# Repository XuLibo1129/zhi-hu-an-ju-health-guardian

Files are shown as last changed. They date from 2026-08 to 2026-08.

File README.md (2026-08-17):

# 基于 ESP32-P4 的多模态 AI 无感健康守护与交互终端系统

面向居家养老、独居老人和家庭健康守护场景的多模态无感监测系统。项目以 ESP32-P4 主终端为数据汇聚和交互中心，融合视觉跌倒检测、毫米波生命体征监测、Wi-Fi CSI 无线感知、语音交互、云端 AI 分析以及电话/短信求助能力，在不要求老人佩戴设备的情况下完成状态感知、风险判断、现场告警和远程查看。

> 本项目曾获**第九届全国大学生嵌入式芯片与系统设计竞赛东部赛区一等奖、全国三等奖（乐鑫赛道）**。

## 项目概览

### 解决的问题

传统手环、胸带等设备需要老人主动佩戴和维护，容易出现忘戴、没电或不适用的问题；单一摄像头方案又容易受到遮挡、光照和隐私因素影响。本项目采用多节点、异构传感器协同的方式，把不同感知手段放在各自擅长的位置：

- **视觉节点**负责识别人体姿态和明显跌倒动作。
- **毫米波雷达节点**负责无接触的人体存在、心率、呼吸率和跌倒辅助判断。
- **Wi-Fi CSI 节点**感知空间信道变化，为遮挡或弱光场景提供辅助证据。
- **ESP32-P4 主终端**负责数据接入、时间门控、融合判断、界面显示、语音交互和告警联动。
- **网页、微信小程序和 Android 客户端**负责远程查看、历史趋势和 AI 健康分析。

### 主要能力

| 能力 | 实现内容 |
| --- | --- |
| 无感生命体征监测 | 展示当前心率、呼吸率、人体存在状态和最近五天历史均值 |
| 多模态跌倒判断 | 视觉与毫米波作为主要证据，Wi-Fi CSI 作为环境辅助证据，并进行数据新鲜度检查 |
| 本地交互 | LVGL 触摸界面、语音唤醒/按住说话、语音播报和现场声光提示 |
| 远程查看 | 主终端通过 HTTP 提供状态与历史数据接口，三端客户端读取同一套数据 |
| AI 健康建议 | 对当前心率、呼吸率、告警状态和环境信息进行简短健康分析与建议 |
| 紧急求助 | 通过蜂窝通信模块执行手动或自动短信、电话告警 |
| 可复现实验 | 提供 CSI 采集、数据清洗、训练、回放和实时推理工具 |

## 系统架构

```mermaid
flowchart LR
    V[视觉节点\nK230 + YOLOv5n] -->|UART 单向状态| M[ESP32-P4 主终端]
    R[毫米波雷达节点\nESP32-P4] -->|HTTP POST| M
    T[ESP32-S3 CSI 发射端] -.->|Wi-Fi CSI 信道变化| X[ESP32-S3 CSI 接收端]
    X -->|特征 UDP| P[电脑端 CSI 推理工具]
    P -->|HTTP POST| M
    M -->|LVGL| S[屏幕与触摸交互]
    M -->|I2S 音频| A[麦克风与扬声器]
    M -->|UART| G[蜂窝通信模块]
    M -->|HTTP API| W[网页 / 微信小程序 / Android]
    M -->|HTTPS| C[LLM / ASR / TTS 服务]
```

### 数据流说明

1. 视觉节点周期性输出 `FALL` 或 `NOFALL` 状态，经 UART 单向发送到主终端。
2. 毫米波节点解析雷达数据，得到人体存在、心率、呼吸率和跌倒状态，经 HTTP 上报主终端。
3. 两块 ESP32-S3 组成 CSI 发射/接收链路，接收端提取 CSI 特征并通过 UDP 发送给电脑端工具。
4. 电脑端模型对 CSI 窗口进行推理、平滑和连续确认，再将结果通过 HTTP 上报主终端。
5. 主终端保存每个节点最近一次有效状态及时间戳，执行超时剔除和融合判断。
6. 主终端更新屏幕、历史数据和告警状态，同时向网页、小程序、Android 端提供查询接口。

## 核心技术路线

### 1. 视觉跌倒检测

视觉节点使用自行采集和标注的数据训练 YOLOv5n，并将模型转换为 K230/CanMV 可运行的 `kmodel`。设备端完成图像采集、推理、目标后处理和状态输出，主终端只接收简洁的状态结果，不传输持续视频流，降低通信负担并减少隐私暴露。

视觉节点脚本位于 `vision/k230/fall_detect.py`。由于摄像头存在倒装安装场景，脚本保留图像方向处理和 UART 状态输出逻辑；模型文件和训练数据不随仓库发布。

### 2. 毫米波生命体征与跌倒辅助判断

毫米波节点独立完成雷达串口接收、帧校验、有效数据解析和状态统计。节点不依赖主终端的实时计算，联网后按周期向 `/api/sensor/ld6002c` 发送 JSON，主终端按时间戳判断数据是否仍然有效。

示例数据：

```json
{
  "sensor": "ld6002c",
  "node_id": "ld6002c_01",
  "human": true,
  "heart_rate": 72.0,
  "breath_rate": 16.0,
  "fall_detected": false,
  "state": "normal",
  "frames": 120
}
```

### 3. Wi-Fi CSI 无线感知

CSI 工具链支持从 ESP32-S3 接收端获取 CSI 数据，完成以下处理：

```text
CSI 原始帧
  -> 解析 I/Q 数据
  -> 窗口切分与统计特征提取
  -> 基线校准与动态阈值
  -> RandomForest / ExtraTrees 模型比较
  -> 概率平滑与连续窗口确认
  -> HTTP 上报主终端
```

工具支持“空房、站立、走路、跌倒、坐下、弯腰捡东西”等动作标签，也支持串口采集、UDP 接收和 CSV 回放。CSI 对房间布局、人体位置、天线方向、热点信道和干扰较敏感，因此在系统中承担**辅助确认**角色，不能脱离视觉和毫米波单独作为最终报警依据。

### 4. 多模态融合与告警策略

主终端对视觉、毫米波和 CSI 分别维护有效标志、更新时间、状态和置信信息。融合前执行时间门控：超过新鲜度窗口、解析失败或通信中断的数据不参与当前判断。

当前工程采用面向嵌入式实时运行的证据组合规则：

- 视觉和毫米波是主要证据，CSI 是辅助证据。
- 单个辅助节点异常时，不直接覆盖主要节点的正常结果。
- 主要节点形成明确跌倒证据，且其他有效节点未明确否定时，进入告警确认。
- 连续窗口确认后才锁存告警，避免瞬时噪声触发。
- 告警锁存期间抑制重复拨号和重复短信；状态恢复并满足解除条件后清除锁存。

这套设计将“传感器判断”和“安全告警动作”分离，避免网络抖动、短时误判或某一个节点掉线直接导致错误报警。详细数据流和接口见 [docs/architecture.md](docs/architecture.md)。

### 5. AI 语音交互

主终端的 AI 能力与跌倒安全链路解耦：

- LLM：回答老人关于天气、日期、新闻和日常问题的对话请求。
- ASR：将麦克风采集的语音转换为文本。
- TTS：将 LLM 回复转换为语音并通过扬声器播放。
- AI 建议：根据当前心率、呼吸率、告警状态和天气生成简短健康建议。

LLM、ASR、TTS 均通过 ESP-IDF `menuconfig` 配置 URL、模型、音色和密钥；未配置云端服务时，传感器、屏幕和本地告警链路仍可独立运行。

## 仓库结构

```text
firmware/
  main-terminal/       ESP32-P4 主终端：UI、HTTP、融合、音频、历史数据和告警
  ld6002c-node/        ESP32-P4 毫米波雷达节点：串口解析和 HTTP 上报
  wifi-csi-tx/         ESP32-S3 CSI 发射端
  wifi-csi-rx/         ESP32-S3 CSI 接收端、CSI 特征输出和网络配置

vision/
  k230/                K230 视觉跌倒检测脚本和部署说明

tools/
  csi-toolkit/         CSI 采集、CSV 修复、数据分析、训练、回放和实时推理

clients/
  web-dashboard/       响应式网页端，支持桌面和手机布局
  wechat-miniapp/      微信小程序端
  android/             Kotlin + Jetpack Compose Android 客户端

hardware/
  enclosures/          主终端、雷达节点和 CSI 节点的可打印外壳文件

docs/
  architecture.md      系统架构、数据流和接口说明
  configuration.md      Wi-Fi、节点、云服务和客户端配置说明
```

## HTTP 接口

主终端默认监听 `8090` 端口，并提供跨域响应头，便于网页、小程序和局域网工具访问。

| 方法 | 路径 | 用途 |
| --- | --- | --- |
| `POST` | `/api/sensor/csi` | 接收 CSI 实时推理结果 |
| `POST` | `/api/sensor/ld6002c` | 接收毫米波节点结果 |
| `GET` | `/api/device/status` | 获取当前心率、呼吸率、节点状态和融合告警状态 |
| `GET` | `/api/device/history` | 获取最近五天历史心率、呼吸率数据 |

CSI 上报示例：

```json
{
  "sensor": "esp32_s3_wifi_csi",
  "node_id": "wifi_csi_01",
  "fall_probability": 0.82,
  "smooth_probability": 0.76,
  "threshold": 0.70,
  "alarm": true,
  "state": "疑似跌倒",
  "samples": 250
}
```

主终端返回的数据面向客户端使用，实际字段以 `app_device_agent.c` 和客户端数据适配代码为准。节点地址、端口和上报周期不要写死在公开源码中，应通过 `menuconfig` 或客户端设置配置。

## 快速开始

### 环境要求

- ESP-IDF 5.5.3，Windows 或 Linux 均可。
- Python 3.10 及以上，CSI 工具建议使用独立虚拟环境。
- K230/CanMV 对应的运行时、摄像头驱动和模型转换工具。
- Android Studio、微信开发者工具和现代浏览器，按需使用对应客户端。
- 实际部署时，主终端、毫米波节点、CSI 节点和电脑应处于同一局域网或手机热点网络。

### 编译 ESP-IDF 固件

先打开对应 ESP-IDF 环境，然后分别进入四个固件工程。以下命令以 PowerShell 为例：

```powershell
cd firmware\main-terminal
idf.py set-target esp32p4
idf.py menuconfig
idf.py build
idf.py -p COM5 flash monitor
```

毫米波节点：

```powershell
cd firmware\ld6002c-node
idf.py set-target esp32p4
idf.py menuconfig
idf.py build
idf.py -p COM13 flash monitor
```

CSI 发射端和接收端：

```powershell
cd firmware\wifi-csi-tx
idf.py set-target esp32s3
idf.py menuconfig
idf.py build

cd ..\wifi-csi-rx
idf.py set-target esp32s3
idf.py menuconfig
idf.py build
```

首次使用必须运行 `idf.py menuconfig`，配置 Wi-Fi、主终端地址、节点 ID、串口引脚和云服务参数。不同硬件版本的闪存大小、芯片修订版本和下载端口可能不同，不要直接照搬其他板卡的烧录参数。

### K230 视觉节点

1. 将训练后转换得到的 `yolov5n-falldown.kmodel` 放到设备存储卡的 `/sdcard/kmodel/`。
2. 根据 CanMV 固件版本安装对应的视觉运行时和摄像头驱动。
3. 将 `vision/k230/fall_detect.py` 上传到 K230 并运行。
4. 将 K230 的 UART TX 接到主终端视觉 UART RX，并连接公共 GND。
5. 确认串口输出为 `K230,FALL` 或 `K230,NOFALL`，再进行主终端联调。

模型权重、训练数据和原始比赛资料不包含在仓库中，需要使用者自行训练或准备兼容 K230 的模型文件。

### CSI 采集与训练

```powershell
cd tools\csi-toolkit
python -m venv .venv
.\.venv\Scripts\Activate.ps1
python -m pip install -r requirements.txt
python csi_viewer.py
```

采集流程：

1. 先启动 ESP32-S3 CSI 接收端。
2. 选择串口或 UDP 数据源，确认 CSI 帧持续到达。
3. 选择动作标签并设置固定采集时长。
4. 采集空房、正常活动、弯腰、跌倒等样本，保存为 UTF-8 BOM CSV。
5. 检查每类样本数量、采集位置和动作一致性。
6. 运行训练脚本并用实时 GUI 进行回放验证。

```powershell
python train_csi_model.py
python csi_realtime_gui.py
```

训练脚本会比较 RandomForest 和 ExtraTrees，并保存表现更好的模型。实际部署前应在最终的 AP/STA 拓扑、房间布局、天线位置和人员距离下重新采集数据，不建议直接使用其他房间的模型。

### 网页客户端

```powershell
cd clients\web-dashboard
python -m http.server 8080
```

浏览器打开 `http://127.0.0.1:8080`，在页面中填写主终端地址，例如 `http://192.168.1.100:8090`。网页支持桌面和手机布局，可查看实时生命体征、融合告警、历史数据和节点信息。

网页端的 DeepSeek 健康分析需要用户在页面中配置自己的 API Key。公开部署时不要把密钥长期放在浏览器端，建议改为受控后端代理或企业级密钥管理服务。

### 微信小程序与 Android 客户端

- 微信小程序工程位于 `clients/wechat-miniapp`，使用微信开发者工具打开该目录。
- Android 工程位于 `clients/android`，使用 Android Studio 打开该目录。
- 两端都需要先将设备和手机接入同一网络，再在设置中填写主终端地址。
- 微信开发者工具调试局域网 HTTP 时，需要按开发者工具要求关闭合法域名校验；正式发布应配置 HTTPS 合法域名。
- Android 工程已允许局域网 HTTP 明文访问，正式部署时建议改为 HTTPS 或受控网关。

Android Debug 构建：

```powershell
cd clients\android
.\gradlew.bat assembleDebug
```

## 配置与安全

详细配置见 [docs/configuration.md](docs/configuration.md)，系统数据流见 [docs/architecture.md](docs/architecture.md)。

以下内容不得提交到 Git：

- Wi-Fi SSID 和密码、真实局域网 IP、热点密码。
- LLM、ASR、TTS、天气和 DeepSeek API Key。
- 紧急联系人手机号、蜂窝通信凭据和 Access Token。
- `sdkconfig`、`.env`、模型权重、原始数据集和包含隐私信息的日志。
- 现场演示专用模拟代码、比赛提交材料和本地语音中转服务。

建议使用 `idf.py menuconfig` 写入本地配置，发布前检查 `git status` 和 `git diff --cached`，确认没有密钥、手机号和真实网络参数。

## 测试与已知限制

当前工程已完成以下基础验证：

- ESP32-P4 主终端、毫米波节点使用 ESP-IDF 5.5.3 构建通过。
- ESP32-S3 CSI 发射端和接收端使用 ESP-IDF 5.5.3 构建通过。
- CSI 采集、训练和实时推理脚本可运行。
- 网页、微信小程序和 Android 客户端均保留主终端状态与历史数据接口。

使用时需要注意：

1. 这是健康守护和安全提醒系统，不是医疗器械，心率、呼吸率和跌倒结果不能替代医生诊断。
2. CSI 结果会受到房间布局、无线干扰、人体位置和天线方向影响，必须进行现场校准。
3. 视觉检测受摄像头视野、遮挡、光照和模型训练数据影响。
4. 毫米波雷达需要稳定供电、正确串口电平和合适安装角度。
5. 云端 AI、ASR、TTS 和天气服务依赖网络，未配置或网络中断时不应影响本地传感器和告警链路。
6. 自动电话和短信属于高风险动作，现场部署前应先使用测试号码并配置重复触发抑制。

## 开源范围

本仓库公开可复现的工程代码、客户端、工具、配置模板、架构文档和 3D 打印外壳文件。以下内容不随仓库发布：

- 训练数据集和模型权重。
- 比赛研究报告、答辩材料和现场演示专用页面。
- 本地语音中转服务、真实密钥、手机号和网络配置。
- 第三方 SDK、字体、模型运行时和传感器厂商资料。

使用第三方组件时，请遵守其原始许可证、服务条款和数据保护要求。

## 许可证

本项目代码、文档和硬件外壳文件采用 [MIT License](LICENSE) 发布。第三方 SDK、字体、模型运行时、开发板资料和传感器资料仍以其原始许可证或厂商条款为准。

欢迎通过 Issue 反馈可复现的问题，也欢迎提交围绕传感器适配、数据处理、客户端体验和部署文档的改进建议。

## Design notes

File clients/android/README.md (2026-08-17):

# 健康守护终端安卓 App

技术栈：

```text
Kotlin + Jetpack Compose + Material 3
```

默认主控地址示例：

```text
http://192.168.1.100:8090
```

用 Android Studio 打开本目录：

```text
当前目录
```

工程已经允许局域网 HTTP 明文访问：

```xml
android:usesCleartextTraffic="true"
```

“AI 健康分析”直接请求 DeepSeek，API Key 在 App 中填写并保存在本机设置中，不会写入项目源码。

使用工程自带的 Gradle Wrapper 构建：

```powershell
.\gradlew.bat assembleDebug
```

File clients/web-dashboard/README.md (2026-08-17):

# 基于 ESP32-P4 的多模态 AI 无感健康守护与交互终端系统

这是面向主终端的真实状态查看网页，支持电脑布局和手机布局。网页从主终端读取生命体征、节点状态、融合结果和最近五天历史数据，也可以在浏览器中直接调用 DeepSeek 对当前数据进行健康分析。

## 使用

1. 将电脑和主终端接入同一局域网。
2. 用静态文件服务器打开当前目录，例如：

   ```powershell
   python -m http.server 8080
   ```

3. 在网页的“主控地址”输入主终端地址，例如 `http://192.168.1.100:8090`。
4. 点击“连接”，确认浏览器允许访问局域网 HTTP 服务。

网页不会内置 API Key。DeepSeek Key 只保存在浏览器本地存储，生产部署时建议通过后端代理或企业密钥管理服务保护密钥。

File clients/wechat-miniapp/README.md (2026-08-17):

# 健康守护终端微信小程序

默认主控地址：

```text
http://192.168.1.100:8090
```

入口页面：

```text
miniprogram/pages/index/index
```

开发者工具中如需访问局域网 HTTP 地址，调试阶段请在详情里关闭“校验合法域名、web-view、TLS 版本以及 HTTPS 证书”。

“AI 健康分析”直接请求 DeepSeek。发布前需要在微信公众平台将以下地址加入 request 合法域名：

```text
https://api.deepseek.com
```

API Key 在小程序页面中填写并保存在微信本地存储，不会写入项目源码。

检查 TypeScript：

```powershell
npm run typecheck
```

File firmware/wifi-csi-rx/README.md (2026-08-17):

# wifi_csi_rx

ESP32-S3 Wi-Fi CSI receiver. It starts a SoftAP, receives UDP packets from the
TX board, enables Wi-Fi CSI, and outputs six-channel CSI features:

```text
rssi,mean_amp2,amp2_8,amp2_24,amp2_48,amp2_80
```

The features can be printed to serial and forwarded to the PC inference tool
over UDP.

When AP+STA is enabled, the A board may also receive CSI from the phone hotspot
router link. The firmware therefore enables `CSI source MAC filter = auto` by
default. In auto mode it prefers MAC addresses of stations connected to the A
board SoftAP, so the B-board link is forwarded and the phone-hotspot link is
dropped. If no SoftAP station is known yet, it falls back to short auto-learning.

Default link:

```text
SSID: CSI_RX_AP
Password: configure it in `idf.py menuconfig` before flashing.
Channel: 6
SoftAP IP: 192.168.4.1
UDP port: 3333
Feature UDP target: configure your computer IP, port 34567
Max clients: 2
```

Keep the PC on the same router/hotspot as the A-board STA and let the PC GUI
listen on UDP port `34567`.

If auto-learning picks the wrong source, set `CSI source MAC filter` in
`idf.py menuconfig` to the B-board MAC, for example:

```text
e0:72:a1:d2:42:68
```

For final deployment, enable AP+STA in `idf.py menuconfig`:

- `Also connect A board to router as STA`: enabled
- `Router STA SSID` / `Router STA password`: router or phone hotspot
- `CSI feature UDP target IP`: PC IP on the router LAN

B board still connects to `CSI_RX_AP`; the PC and main ESP32-P4 terminal stay
on the router network.

Build:

```powershell
idf.py set-target esp32s3
idf.py build
```

Expected serial output:

```text
-42,1234,99,1200,880,240
I (...) wifi_csi_rx: STAT csi_hz=50 udp_hz=50 forward_hz=50 ...
```

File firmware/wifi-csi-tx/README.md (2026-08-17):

# wifi_csi_tx

ESP32-S3 Wi-Fi CSI transmitter. It connects to the receiver SoftAP and sends
UDP packets at a fixed interval so the receiver can collect CSI.

Default link:

```text
SSID: CSI_RX_AP
Password: configure it in `idf.py menuconfig` before flashing.
Receiver IP: 192.168.4.1
UDP port: 3333
Packet interval: 20 ms
```

Build:

```powershell
idf.py set-target esp32s3
idf.py build
```

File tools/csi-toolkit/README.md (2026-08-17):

# ESP32 CSI 无线感知波形工具

这是给 ESP32-S3 Wi-Fi CSI 接收端用的串口波形工具，支持实时看波形、切换动作标签、保存 CSV 数据。

支持的串口格式：

```text
-25,1830,244,185,3200,4100
CSI_DATA,1,aa:bb:cc:dd:ee:ff,-42,...,[...]
```

启动：

```powershell
cd D:\Users\XLB\Desktop\esp32_csi_viewer
.\run.ps1
```

使用：

1. A 板烧录并运行 `wifi_csi_rx`。
2. 启动 `csi_viewer.py`，或直接运行 `run.ps1`。
3. 选择 A 板 COM 口，波特率保持 `115200`，点击“连接”。
4. 采集前选择“空房”“走路”“坐下”“跌倒”“弯腰捡东西”等标签。
5. 设置“采集时长(s)”，点击“开始记录”保存 CSV 数据，到时间会自动停止，默认放在 `data` 文件夹。
6. CSV 使用带 BOM 的 UTF-8 保存，直接用 Excel 打开中文不会乱码。

如果之前保存过乱码 CSV，可以转换旧文件：

```powershell
cd D:\Users\XLB\Desktop\esp32_csi_viewer
python .\fix_csv_encoding.py
```

训练 Wi-Fi CSI 辅助跌倒模型：

```powershell
cd D:\Users\XLB\Desktop\esp32_csi_viewer
python .\train_csi_model.py
```

默认训练二分类模型：`fall` / `non_fall`。输出会保存到 `models` 文件夹。

默认训练会自动比较随机森林和 ExtraTrees，并选择交叉验证表现更好的模型。当前建议稳定运行阈值是 `0.50`，适合作为主终端融合视觉/雷达时的辅助信号。如果只想查看六分类效果：

```powershell
python .\train_csi_model.py --mode multiclass
```

实时推理：

推荐直接打开图形界面：

```powershell
.\start_realtime_gui.bat
```

也可以手动运行：

```powershell
python .\csi_realtime_gui.py
```

界面里可以选择 A 板串口、选择模型、调阈值、调连续确认窗口，并实时查看跌倒概率。
实时推理现在带有开场环境校准和运动门控。点击“开始UDP接收”后，前几个校准窗口内尽量保持空房/无人移动，让软件学习当前 AP+STA、手机热点和房间状态的基线。日志里的“动态阈值”会随基线自动抬高，用来压住空房误报。

如果 A 板不想一直插电脑串口，可以走 UDP：

1. A 板 `wifi_csi_rx` 当前把六路特征发送到电脑的 `34567` UDP 端口。
2. 电脑与 A 板 STA 连接同一个路由器或手机热点。
3. 打开实时推理界面后会自动监听 UDP `34567`；停止后也可手动点击“开始UDP接收”。
4. B 板继续连接 A 板热点并发送 UDP 包，界面收到数据后会直接进入模型判断。

命令行 UDP 接收也可以这样运行：

```powershell
python .\csi_realtime_infer.py --udp-port 34567
```

正式接主终端时建议切到同一个路由器网络：

1. 电脑、主终端 ESP32-P4 连接同一个 2.4GHz 路由器/手机热点。
2. A 板在 `idf.py menuconfig` 里打开 `Also connect A board to router as STA`，填路由器 SSID/密码。
3. 把 `CSI feature UDP target IP` 从默认 `192.168.4.255` 改成电脑在路由器里的 IP。
4. B 板仍然只连接 A 板热点 `CSI_RX_AP`，不需要改。
5. GUI 继续点“开始UDP接收”，识别结果再通过“主终端URL”发给 ESP32-P4。

如果 AP+STA 模式下效果仍然差，直接在最终拓扑下补采数据：

1. 打开 `csi_viewer.py` 或 `run.ps1`。
2. 不选串口，UDP端口保持 `34567`，点击“UDP连接”。
3. 在当前 A板AP+STA、B板连接A板、电脑连接手机热点的状态下，重新采集 `空房`、`站立`、`走路`、`跌倒` 等短样本。
4. 重新运行 `python .\train_csi_model.py`，再用最新模型做实时测试。

发送结果到主终端：

1. 主终端开一个 HTTP 接收接口，例如 `http://主终端IP:8090/api/sensor/csi`。
2. 在实时推理界面的“主终端URL”里填入这个地址。
3. 点击“测试发送”，日志显示成功后再开始实时检测。

发送的 JSON 格式大致如下：

```json
{
  "sensor": "esp32_s3_wifi_csi",
  "node_id": "wifi_csi_01",
  "time": "2026-07-06T15:56:00",
  "fall_probability": 0.82,
  "smooth_probability": 0.76,
  "threshold": 0.70,
  "alarm": true,
  "state": "疑似跌倒",
  "samples": 250
}
```

命令行版本仍然保留：

```powershell
python .\csi_realtime_infer.py --port COM8
```

把 `COM8` 换成 A 板实际串口。脚本会加载 `models` 文件夹里最新的二分类模型，输出 `p_fall`、平滑概率和 `正常/预警中/疑似跌倒`。默认阈值是 `0.50`，连续 4 个窗口超过阈值才报警。GUI 里也提供“稳定运行”和“灵敏测试”两个预设按钮。

如果现场仍然误报，先用更保守的参数：

```powershell
python .\csi_realtime_infer.py --port COM8 --threshold 0.85 --confirm-windows 6
```

用已有 CSV 回放测试：

```powershell
python .\csi_realtime_infer.py --replay .\data\csi_20260706_152250_跌倒.csv --print-normal
```

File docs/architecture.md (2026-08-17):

# 系统架构

## 数据流

```text
K230 视觉节点 ──UART──┐
毫米波雷达节点 ─HTTP──┼──> ESP32-P4 主终端 ──HTTP/局域网──> Web / 小程序 / Android
CSI 接收端 ──HTTP─────┘             │
                                    ├──LVGL 触摸界面
                                    ├──SD 卡历史心率/呼吸率
                                    ├──A7670C 电话/短信
                                    └──云端 LLM / ASR / TTS
```

## 主终端职责

主终端只保存各节点最近一次有效数据，并为每条数据记录时间戳。节点超过新鲜度窗口后不会继续参与跌倒判定。融合流程包含：

1. 读取视觉、毫米波和 CSI 的有效状态。
2. 对超时、无效和通信中断数据做时间门控。
3. 视觉和毫米波作为主证据，CSI 作为辅助证据；主终端依据有效证据组合生成融合分数。
4. 达到阈值后进行告警锁存，避免同一事件重复触发；恢复正常后解除锁存。

CSI 的训练和窗口特征提取在 `tools/csi-toolkit` 中完成。由于 CSI 对环境、天线摆放和信道变化敏感，它在系统中承担辅助确认作用，不单独决定最终告警。

## 节点接口

- K230：主终端 UART RX 接收 K230 的单向状态行，建议格式为 `K230,FALL` 或 `K230,NOFALL`。
- 毫米波节点：周期性向主终端 `POST /api/sensor/ld6002c` 发送 JSON。
- CSI 推理工具：周期性向主终端 `POST /api/sensor/csi` 发送 JSON。
- 主终端：提供 `GET /api/device/status` 和 `GET /api/device/history`，供三端客户端读取。

## AI 交互

AI 功能与跌倒安全链路解耦。LLM 负责对话和健康建议，ASR 负责语音转写，TTS 负责播放文本；三者都通过 menuconfig 配置 URL、模型和密钥，未配置时主终端仍可运行本地界面和传感器链路。

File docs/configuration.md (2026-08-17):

# 配置说明

## 主终端

进入 `firmware/main-terminal` 后执行 `idf.py menuconfig`，重点配置：

- `Dual Agent Console -> Wi-Fi SSID / password`
- `Cloud LLM -> URL / model / API key`
- `Cloud ASR -> URL / model / API key`
- `Cloud TTS -> URL / model / voice / API key`
- `A7670C -> emergency phone`，以及自动短信、自动电话开关
- `K230 vision UART` 和 `Radar UART` 引脚

主终端默认天气位置是南京市江北新区；经纬度和天气站点可以在 menuconfig 调整。

## 毫米波节点

在 `firmware/ld6002c-node` 配置：

- Wi-Fi SSID 和密码
- 主终端 URL，例如 `http://192.168.1.100:8090/api/sensor/ld6002c`
- 节点 ID、UART 引脚和上报周期

仓库中的 `192.168.1.100` 只是示例地址，必须换成实际主终端地址。

## CSI 节点

接收端建立 SoftAP，发射端连接该 AP。接收端可选用 STA 同时连接路由器或手机热点，再把特征 UDP 发到电脑。电脑端推理工具将判定结果通过 HTTP 发给主终端。

不要把真实 Wi-Fi 密码、电脑 IP 或主终端 IP 写入源码。推荐在 `idf.py menuconfig` 中设置，发布前保留 `sdkconfig.defaults` 中的空值或示例值。

## K230

将 YOLOv5n 跌倒检测模型以 `yolov5n-falldown.kmodel` 放在设备的 `/sdcard/kmodel/` 下，再运行 `vision/k230/fall_detect.py`。模型权重不在仓库中；需要根据 K230/CanMV 版本安装相应运行时和驱动。

## 客户端

网页、小程序和 Android 默认使用 `http://192.168.1.100:8090` 作为示例地址。实际使用时在网页输入框、小程序设置或 Android 设置页中修改为主终端当前地址。移动端访问局域网 HTTP 服务时，还需要满足微信开发者工具、Android 明文流量和目标网络的权限要求。

## 密钥管理

API Key、Access Token、手机号和语音服务凭据只能放在本地配置或受控服务中。不要把它们写入 Git、截图、日志、README 或固件二进制。

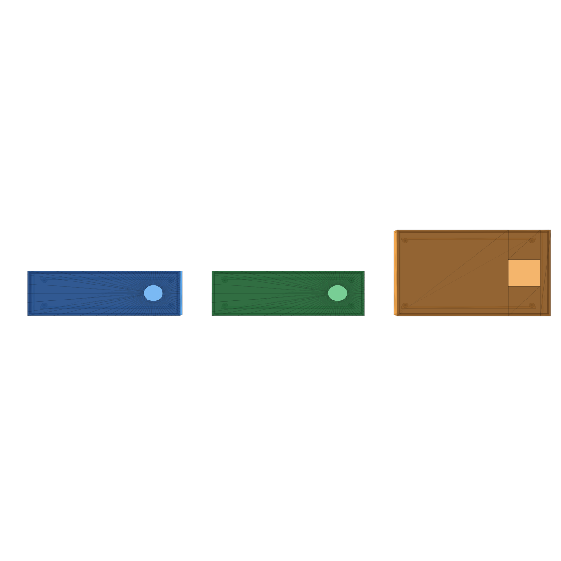
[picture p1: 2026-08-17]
hardware/enclosures/sensor-nodes/??????_????.png

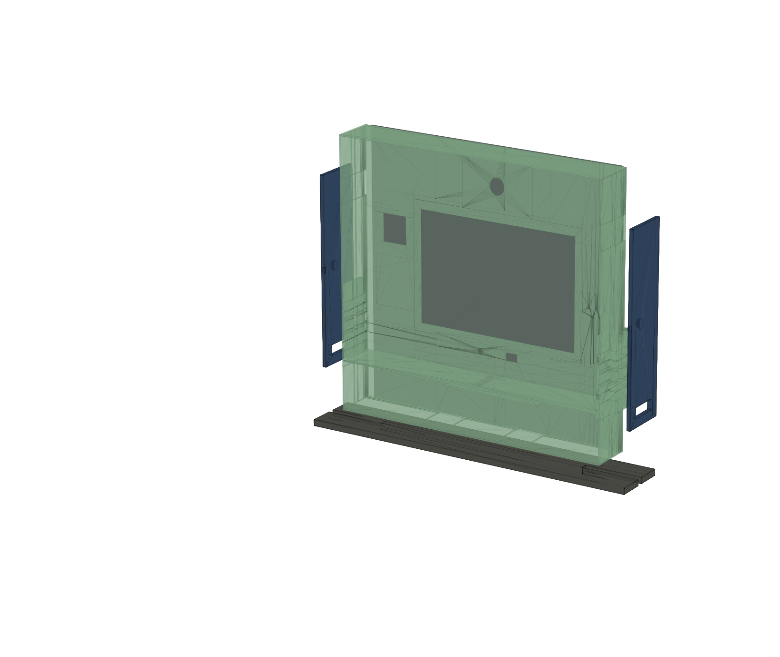
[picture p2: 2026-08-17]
hardware/enclosures/main-terminal/????_????.png

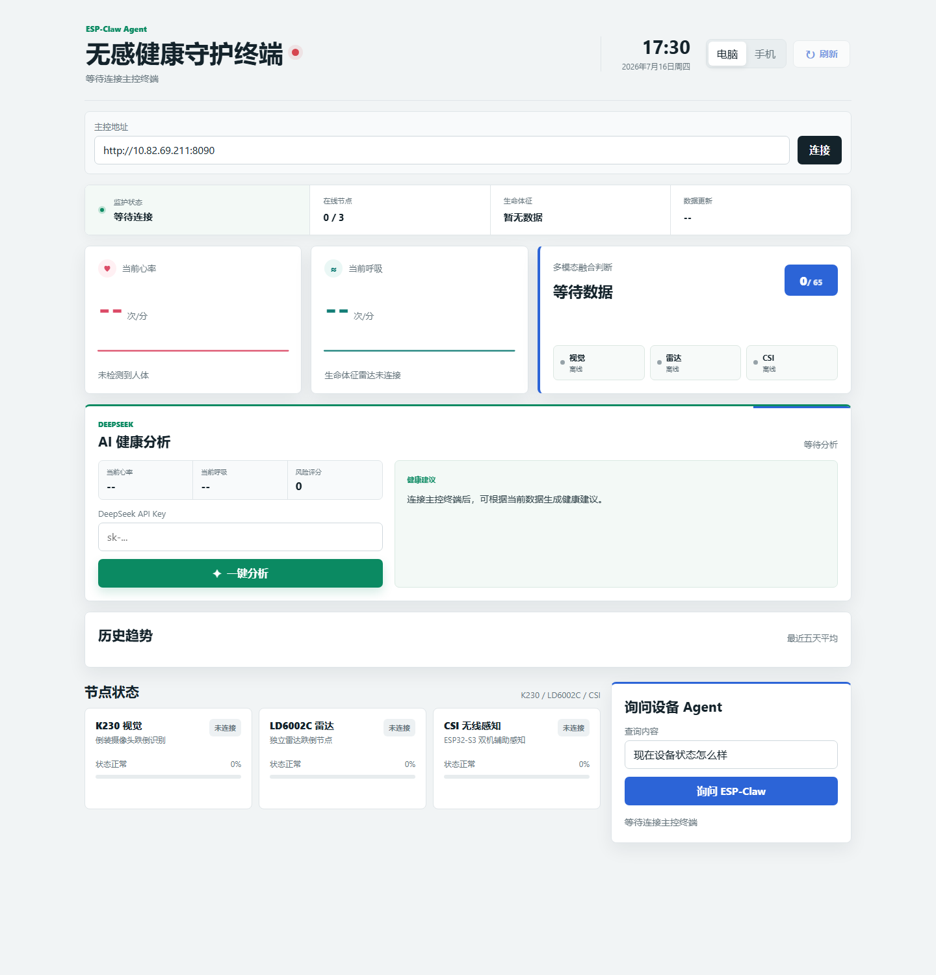
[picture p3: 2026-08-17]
clients/web-dashboard/dashboard-desktop.png

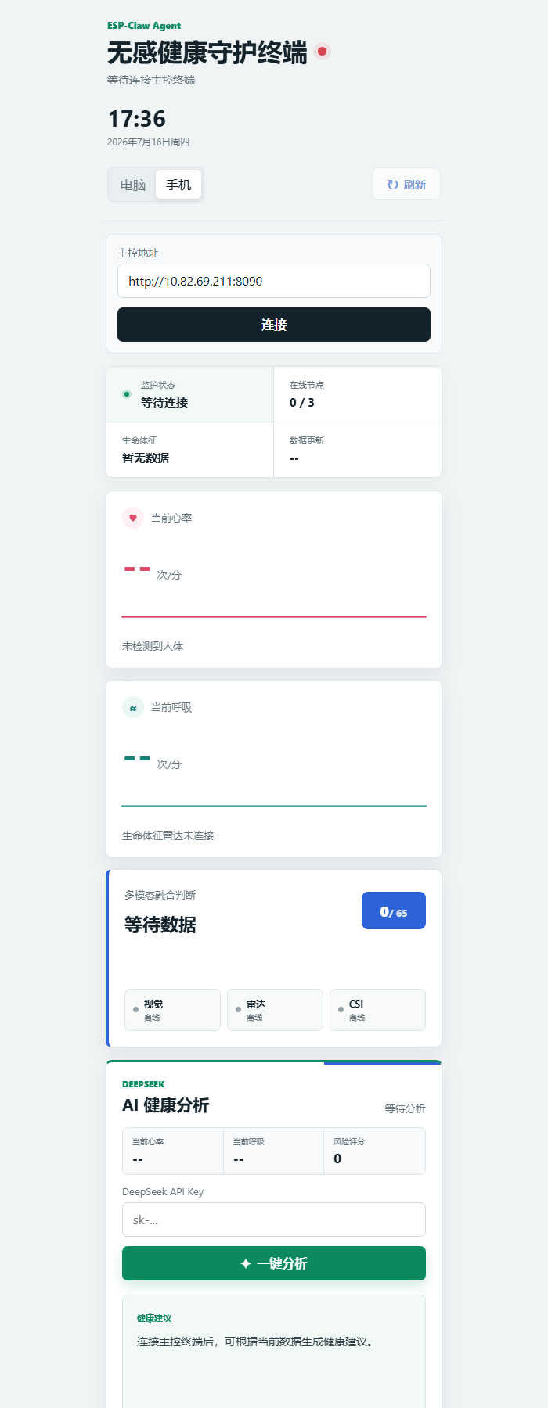
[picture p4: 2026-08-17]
clients/web-dashboard/dashboard-phone-mode.png

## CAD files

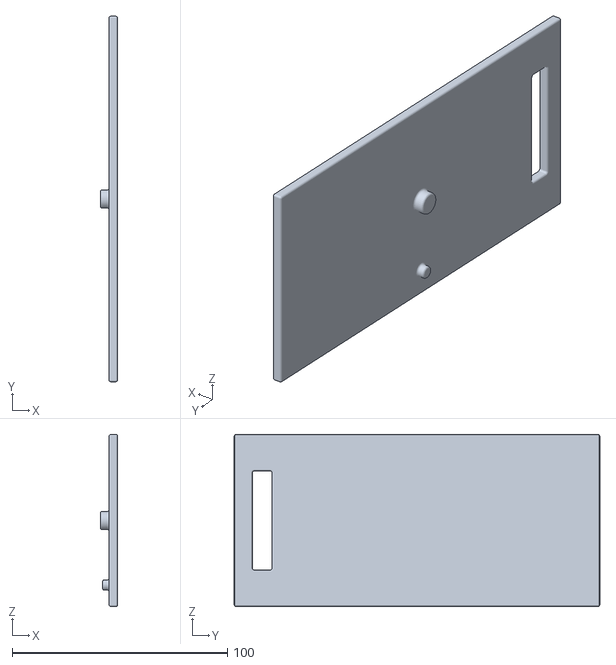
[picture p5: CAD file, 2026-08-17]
hardware/enclosures/main-terminal/???_??2?_?????.STL
8.00 x 170.0 x 80.0

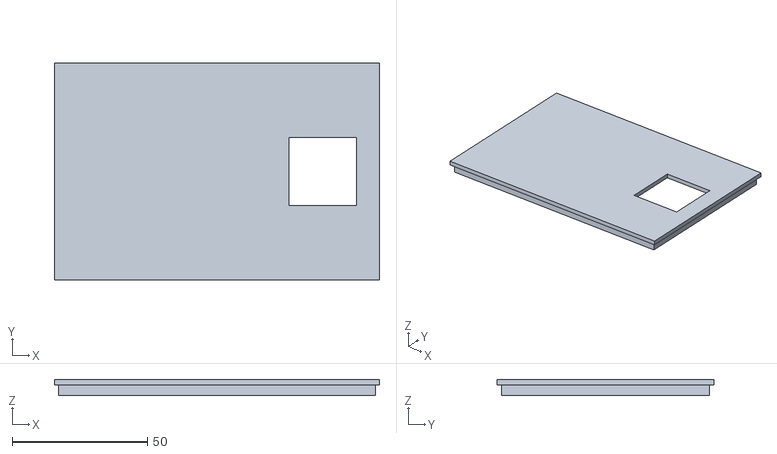
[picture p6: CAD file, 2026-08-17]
hardware/enclosures/sensor-nodes/LD6002????_??_25x25??.STL
120.0 x 80.0 x 6.00

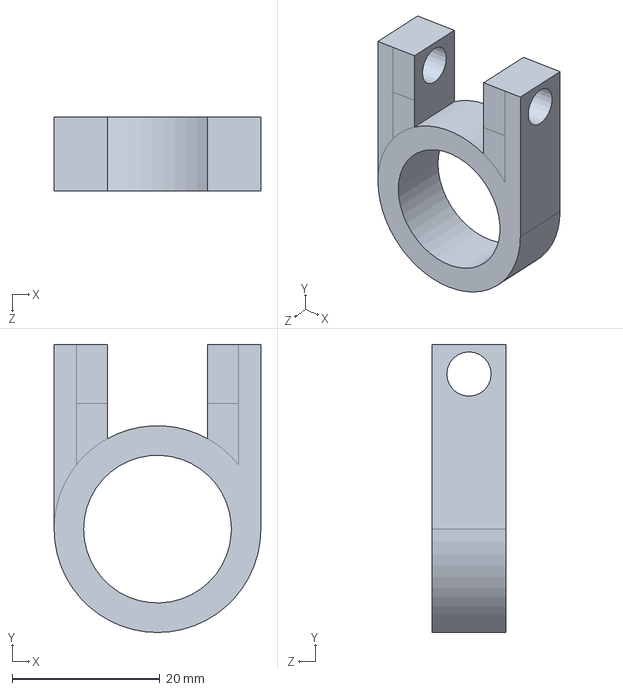
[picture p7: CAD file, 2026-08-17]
hardware/enclosures/main-terminal/???????.SLDPRT
28.0 x 39.0 x 10.0 mm

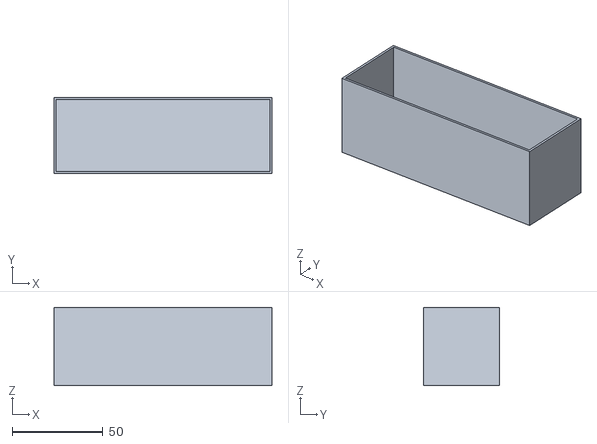
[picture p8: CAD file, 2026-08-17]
hardware/enclosures/sensor-nodes/WiFi_CSI_A??_??_?????.STL
120.0 x 42.0 x 43.0

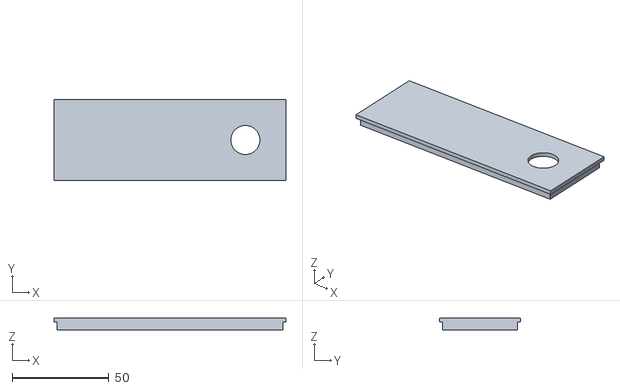
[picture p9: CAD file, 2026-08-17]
hardware/enclosures/sensor-nodes/WiFi_CSI_A??_??_15mm??.STL
120.0 x 42.0 x 6.00

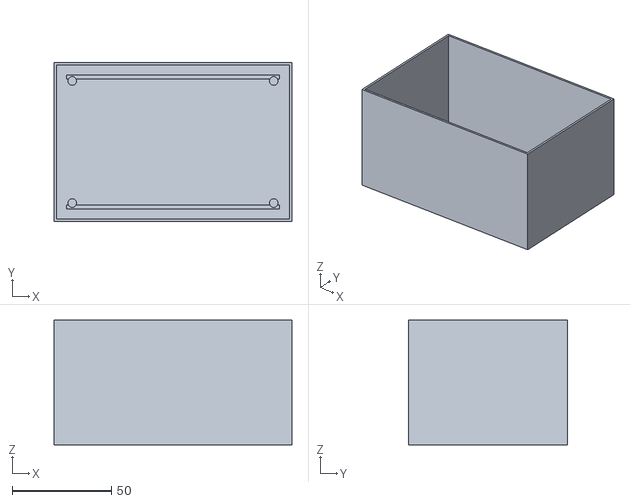
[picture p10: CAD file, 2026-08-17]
hardware/enclosures/sensor-nodes/LD6002????_??_?????.STL
120.0 x 80.0 x 63.0

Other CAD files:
hardware/enclosures/sensor-nodes/WiFi_CSI_B??_??_15mm??.STL
hardware/enclosures/sensor-nodes/WiFi_CSI_B??_??_?????.STL
hardware/enclosures/main-terminal/????_????.STL
hardware/enclosures/main-terminal/????_????_??????.STL
hardware/enclosures/main-terminal/????_???_?????_?????.STL

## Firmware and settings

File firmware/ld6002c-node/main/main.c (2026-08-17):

#include <inttypes.h>
#include <stdbool.h>
#include <stdint.h>
#include <stdio.h>
#include <string.h>

#include "driver/gpio.h"
#include "driver/uart.h"
#include "esp_check.h"
#include "esp_err.h"
#include "esp_event.h"
#include "esp_http_client.h"
#include "esp_log.h"
#include "esp_netif.h"
#include "esp_timer.h"
#include "esp_wifi.h"
#include "freertos/FreeRTOS.h"
#include "freertos/event_groups.h"
#include "freertos/task.h"
#include "nvs_flash.h"

#ifndef CONFIG_APP_WIFI_SSID
#define CONFIG_APP_WIFI_SSID ""
#endif

#ifndef CONFIG_APP_WIFI_PASSWORD
#define CONFIG_APP_WIFI_PASSWORD ""
#endif

#ifndef CONFIG_APP_MAIN_TERMINAL_URL
#define CONFIG_APP_MAIN_TERMINAL_URL ""
#endif

#ifndef CONFIG_APP_NODE_ID
#define CONFIG_APP_NODE_ID "ld6002c_01"
#endif

#ifndef CONFIG_APP_LD6002C_UART_NUM
#define CONFIG_APP_LD6002C_UART_NUM 1
#endif

#ifndef CONFIG_APP_LD6002C_UART_TX_GPIO
#define CONFIG_APP_LD6002C_UART_TX_GPIO 23
#endif

#ifndef CONFIG_APP_LD6002C_UART_RX_GPIO
#define CONFIG_APP_LD6002C_UART_RX_GPIO 22
#endif

#ifndef CONFIG_APP_LD6002C_UART_BAUD
#define CONFIG_APP_LD6002C_UART_BAUD 115200
#endif

#ifndef CONFIG_APP_LD6002C_TX2_GPIO
#define CONFIG_APP_LD6002C_TX2_GPIO -1
#endif

#ifndef CONFIG_APP_REPORT_INTERVAL_MS
#define CONFIG_APP_REPORT_INTERVAL_MS 2000
#endif

#ifndef CONFIG_APP_HTTP_TIMEOUT_MS
#define CONFIG_APP_HTTP_TIMEOUT_MS 2000
#endif

#ifndef CONFIG_APP_LD6002C_QUERY_FIRMWARE_ON_BOOT
#define CONFIG_APP_LD6002C_QUERY_FIRMWARE_ON_BOOT 1
#endif

#define WIFI_CONNECTED_BIT BIT0
#define WIFI_FAIL_BIT      BIT1

#define LD6002C_SOF              0x01
#define LD6002C_MAX_PAYLOAD      256
#define LD6002C_RX_BUF_SIZE      2048
#define LD6002C_TYPE_FIRMWARE    0xFFFF
#define LD6002C_TYPE_FALL_STATUS 0x0E02

static const char *TAG = "ld6002c_node";

typedef struct {
    bool valid;
    bool fall_detected;
    bool uart_valid;
    bool uart_fall;
    bool tx2_valid;
    bool tx2_fall;
    uint32_t frame_count;
    uint32_t fall_count;
    uint32_t header_error_count;
    uint32_t data_error_count;
    int64_t last_update_ms;
    char source[12];
} app_state_t;

typedef enum {
    TF_WAIT_SOF = 0,
    TF_READ_HEADER,
    TF_READ_DATA,
} tf_state_t;

typedef struct {
    tf_state_t state;
    uint8_t header[8];
    size_t header_pos;
    uint16_t payload_len;
    uint16_t type;
    uint8_t payload[LD6002C_MAX_PAYLOAD + 1];
    size_t payload_pos;
} tf_parser_t;

static EventGroupHandle_t s_wifi_event_group;
static portMUX_TYPE s_state_lock = portMUX_INITIALIZER_UNLOCKED;
static app_state_t s_state;
static volatile bool s_wifi_ready;
static int s_wifi_retry_count;
static uint16_t s_tx_id = 1;

static uart_port_t radar_uart(void)
{
    return (uart_port_t)CONFIG_APP_LD6002C_UART_NUM;
}

static int64_t now_ms(void)
{
    return esp_timer_get_time() / 1000;
}

static uint8_t tf_checksum(const uint8_t *data, size_t len)
{
    uint8_t ret = 0;
    for (size_t i = 0; i < len; ++i) {
        ret ^= data[i];
    }
    return (uint8_t)~ret;
}

static uint16_t be16(const uint8_t *p)
{
    return ((uint16_t)p[0] << 8) | p[1];
}

static void put_be16(uint8_t *p, uint16_t value)
{
    p[0] = (uint8_t)(value >> 8);
    p[1] = (uint8_t)value;
}

static void refresh_overall_locked(const char *source)
{
    bool fall = (s_state.uart_valid && s_state.uart_fall) ||
                (s_state.tx2_valid && s_state.tx2_fall);

    if (fall && !s_state.fall_detected) {
        s_state.fall_count++;
    }

    s_state.valid = s_state.uart_valid || s_state.tx2_valid;
    s_state.fall_detected = fall;
    s_state.last_update_ms = now_ms();
    snprintf(s_state.source, sizeof(s_state.source), "%s", source ? source : "-");
}

static void update_uart_fall(bool fall)
{
    bool first_report;
    bool changed;
    bool previous;

    portENTER_CRITICAL(&s_state_lock);
    first_report = !s_state.uart_valid;
    previous = s_state.uart_fall;
    changed = first_report || previous != fall;
    s_state.uart_valid = true;
    s_state.uart_fall = fall;
    s_state.frame_count++;
    refresh_overall_locked("uart");
    portEXIT_CRITICAL(&s_state_lock);

    if (changed) {
        if (first_report) {
            ESP_LOGI(TAG, "LD6002C UART initial fall=%d", fall);
        } else {
            ESP_LOGW(TAG, "LD6002C UART fall changed: %d -> %d", previous, fall);
        }
    }
}

#if CONFIG_APP_LD6002C_TX2_GPIO >= 0
static void update_tx2_fall(bool fall)
{
    bool first_report;
    bool changed;
    bool previous;

    portENTER_CRITICAL(&s_state_lock);
    first_report = !s_state.tx2_valid;
    previous = s_state.tx2_fall;
    changed = first_report || previous != fall;
    s_state.tx2_valid = true;
    s_state.tx2_fall = fall;
    refresh_overall_locked("tx2");
    portEXIT_CRITICAL(&s_state_lock);

    if (changed) {
        if (first_report) {
            ESP_LOGI(TAG, "LD6002C TX2 initial fall=%d", fall);
        } else {
            ESP_LOGW(TAG, "LD6002C TX2 fall changed: %d -> %d", previous, fall);
        }
    }
}
#endif

static void count_header_error(void)
{
    portENTER_CRITICAL(&s_state_lock);
    s_state.header_error_count++;
    portEXIT_CRITICAL(&s_state_lock);
}

static void count_data_error(void)
{
    portENTER_CRITICAL(&s_state_lock);
    s_state.data_error_count++;
    portEXIT_CRITICAL(&s_state_lock);
}

static app_state_t get_state_snapshot(void)
{
    app_state_t copy;
    portENTER_CRITICAL(&s_state_lock);
    copy = s_state;
    portEXIT_CRITICAL(&s_state_lock);
    return copy;
}

static void dispatch_frame(uint16_t type, const uint8_t *payload, uint16_t len)
{
    if (type == LD6002C_TYPE_FALL_STATUS) {
        if (len < 1 || payload == NULL) {
            ESP_LOGW(TAG, "fall status frame too short: len=%u", len);
            return;
        }
        update_uart_fall(payload[0] != 0);
        return;
    }

    if (type == LD6002C_TYPE_FIRMWARE) {
        ESP_LOGI(TAG, "firmware response len=%u", len);
        return;
    }

    ESP_LOGD(TAG, "frame type=0x%04X len=%u", type, len);
}

static void parser_reset(tf_parser_t *parser)
{
    parser->state = TF_WAIT_SOF;
    parser->header_pos = 0;
    parser->payload_len = 0;
    parser->type = 0;
    parser->payload_pos = 0;
}

static void parser_feed(tf_parser_t *parser, uint8_t byte)
{
    switch (parser->state) {
    case TF_WAIT_SOF:
        if (byte == LD6002C_SOF) {
            parser->header[0] = byte;
            parser->header_pos = 1;
            parser->state = TF_READ_HEADER;
        }
        break;

    case TF_READ_HEADER:
        parser->header[parser->header_pos++] = byte;
        if (parser->header_pos < sizeof(parser->header)) {
            break;
        }

        if (tf_checksum(parser->header, 7) != parser->header[7]) {
            count_header_error();
            ESP_LOGW(TAG, "header checksum mismatch");
            parser_reset(parser);
            if (byte == LD6002C_SOF) {
                parser_feed(parser, byte);
            }
            break;
        }

        parser->payload_len = be16(&parser->header[3]);
        parser->type = be16(&parser->header[5]);
        if (parser->payload_len > LD6002C_MAX_PAYLOAD) {
            count_data_error();
            ESP_LOGW(TAG, "payload too long: %u", parser->payload_len);
            parser_reset(parser);
            break;
        }

        if (parser->payload_len == 0) {
            dispatch_frame(parser->type, NULL, 0);
            parser_reset(parser);
        } else {
            parser->payload_pos = 0;
            parser->state = TF_READ_DATA;
        }
        break;

    case TF_READ_DATA:
        parser->payload[parser->payload_pos++] = byte;
        if (parser->payload_pos < (size_t)parser->payload_len + 1) {
            break;
        }

        if (tf_checksum(parser->payload, parser->payload_len) !=
            parser->payload[parser->payload_len]) {
            count_data_error();
            ESP_LOGW(TAG, "data checksum mismatch type=0x%04X len=%u",
                     parser->type, parser->payload_len);
        } else {
            dispatch_frame(parser->type, parser->payload, parser->payload_len);
        }
        parser_reset(parser);
        break;
    }
}

static esp_err_t tf_send(uint16_t type, const uint8_t *payload, uint16_t len)
{
    uint8_t frame[8 + LD6002C_MAX_PAYLOAD + 1];
    if (len > LD6002C_MAX_PAYLOAD) {
        return ESP_ERR_INVALID_SIZE;
    }

    frame[0] = LD6002C_SOF;
    put_be16(&frame[1], s_tx_id++);
    put_be16(&frame[3], len);
    put_be16(&frame[5], type);
    frame[7] = tf_checksum(frame, 7);

    size_t frame_len = 8;
    if (len > 0) {
        memcpy(&frame[8], payload, len);
        frame[8 + len] = tf_checksum(payload, len);
        frame_len += (size_t)len + 1;
    }

    int written = uart_write_bytes(radar_uart(), frame, frame_len);
    if (written != (int)frame_len) {
        return ESP_FAIL;
    }

    ESP_LOGI(TAG, "TX type=0x%04X len=%u", type, len);
    return ESP_OK;
}

static esp_err_t radar_start(void)
{
    const uart_config_t uart_config = {
        .baud_rate = CONFIG_APP_LD6002C_UART_BAUD,
        .data_bits = UART_DATA_8_BITS,
        .parity = UART_PARITY_DISABLE,
        .stop_bits = UART_STOP_BITS_1,
        .flow_ctrl = UART_HW_FLOWCTRL_DISABLE,
        .rx_flow_ctrl_thresh = 0,
        .source_clk = UART_SCLK_DEFAULT,
    };

    ESP_RETURN_ON_ERROR(uart_driver_install(radar_uart(), LD6002C_RX_BUF_SIZE, 0, 0, NULL, 0),
                        TAG, "uart_driver_install failed");
    ESP_RETURN_ON_ERROR(uart_param_config(radar_uart(), &uart_config),
                        TAG, "uart_param_config failed");
    ESP_RETURN_ON_ERROR(uart_set_pin(radar_uart(),
                                     CONFIG_APP_LD6002C_UART_TX_GPIO,
                                     CONFIG_APP_LD6002C_UART_RX_GPIO,
                                     UART_PIN_NO_CHANGE,
                                     UART_PIN_NO_CHANGE),
                        TAG, "uart_set_pin failed");
    uart_flush_input(radar_uart());

    ESP_LOGI(TAG, "LD6002C UART started: UART=%d baud=%d TX=%d RX=%d",
             CONFIG_APP_LD6002C_UART_NUM,
             CONFIG_APP_LD6002C_UART_BAUD,
             CONFIG_APP_LD6002C_UART_TX_GPIO,
             CONFIG_APP_LD6002C_UART_RX_GPIO);
    return ESP_OK;
}

static void radar_rx_task(void *arg)
{
    (void)arg;
    uint8_t buf[128];
    tf_parser_t parser = {0};
    parser_reset(&parser);

    while (true) {
        int len = uart_read_bytes(radar_uart(), buf, sizeof(buf), pdMS_TO_TICKS(200));
        if (len <= 0) {
            continue;
        }

        for (int i = 0; i < len; ++i) {
            parser_feed(&parser, buf[i]);
        }
    }
}

static void tx2_poll_task(void *arg)
{
    (void)arg;
#if CONFIG_APP_LD6002C_TX2_GPIO >= 0
    gpio_config_t io_conf = {
        .pin_bit_mask = 1ULL << CONFIG_APP_LD6002C_TX2_GPIO,
        .mode = GPIO_MODE_INPUT,
        .pull_up_en = GPIO_PULLUP_DISABLE,
        .pull_down_en = GPIO_PULLDOWN_DISABLE,
        .intr_type = GPIO_INTR_DISABLE,
    };
    ESP_ERROR_CHECK(gpio_config(&io_conf));

    int last_level = -1;
    while (true) {
        int level = gpio_get_level(CONFIG_APP_LD6002C_TX2_GPIO);
        if (level != last_level) {
            last_level = level;
            update_tx2_fall(level != 0);
        }
        vTaskDelay(pdMS_TO_TICKS(100));
    }
#else
    ESP_LOGI(TAG, "LD6002C TX2 GPIO disabled");
    vTaskDelete(NULL);
#endif
}

static void wifi_event_handler(void *arg, esp_event_base_t event_base,
                               int32_t event_id, void *event_data)
{
    (void)arg;

    if (event_base == WIFI_EVENT && event_id == WIFI_EVENT_STA_START) {
        esp_wifi_connect();
    } else if (event_base == WIFI_EVENT && event_id == WIFI_EVENT_STA_DISCONNECTED) {
        s_wifi_ready = false;
        if (s_wifi_retry_count < 100) {
            esp_wifi_connect();
            s_wifi_retry_count++;
            ESP_LOGW(TAG, "Wi-Fi reconnecting, retry=%d", s_wifi_retry_count);
        } else {
            xEventGroupSetBits(s_wifi_event_group, WIFI_FAIL_BIT);
        }
    } else if (event_base == IP_EVENT && event_id == IP_EVENT_STA_GOT_IP) {
        ip_event_got_ip_t *event = (ip_event_got_ip_t *)event_data;
        s_wifi_retry_count = 0;
        s_wifi_ready = true;
        ESP_LOGI(TAG, "Wi-Fi got IP: " IPSTR, IP2STR(&event->ip_info.ip));
        xEventGroupSetBits(s_wifi_event_group, WIFI_CONNECTED_BIT);
    }
}

static esp_err_t wifi_start(void)
{
    if (strlen(CONFIG_APP_WIFI_SSID) == 0) {
        ESP_LOGW(TAG, "Wi-Fi SSID is empty");
        return ESP_ERR_INVALID_STATE;
    }

    s_wifi_event_group = xEventGroupCreate();
    if (s_wifi_event_group == NULL) {
        return ESP_ERR_NO_MEM;
    }

    esp_err_t ret = nvs_flash_init();
    if (ret == ESP_ERR_NVS_NO_FREE_PAGES || ret == ESP_ERR_NVS_NEW_VERSION_FOUND) {
        ESP_ERROR_CHECK(nvs_flash_erase());
        ret = nvs_flash_init();
    }
    ESP_RETURN_ON_ERROR(ret, TAG, "nvs_flash_init failed");
    ESP_RETURN_ON_ERROR(esp_netif_init(), TAG, "esp_netif_init failed");

    ret = esp_event_loop_create_default();
    if (ret != ESP_OK && ret != ESP_ERR_INVALID_STATE) {
        ESP_RETURN_ON_ERROR(ret, TAG, "esp_event_loop_create_default failed");
    }

    esp_netif_create_default_wifi_sta();

    wifi_init_config_t cfg = WIFI_INIT_CONFIG_DEFAULT();
    ESP_RETURN_ON_ERROR(esp_wifi_init(&cfg), TAG, "esp_wifi_init failed");
    ESP_RETURN_ON_ERROR(esp_event_handler_instance_register(WIFI_EVENT, ESP_EVENT_ANY_ID,
                                                            wifi_event_handler, NULL, NULL),
                        TAG, "register WIFI_EVENT failed");
    ESP_RETURN_ON_ERROR(esp_event_handler_instance_register(IP_EVENT, IP_EVENT_STA_GOT_IP,
                                                            wifi_event_handler, NULL, NULL),
                        TAG, "register IP_EVENT failed");

    wifi_config_t wifi_config = {0};
    strlcpy((char *)wifi_config.sta.ssid, CONFIG_APP_WIFI_SSID, sizeof(wifi_config.sta.ssid));
    strlcpy((char *)wifi_config.sta.password, CONFIG_APP_WIFI_PASSWORD, sizeof(wifi_config.sta.password));
    wifi_config.sta.threshold.authmode = strlen(CONFIG_APP_WIFI_PASSWORD) > 0 ? WIFI_AUTH_WPA2_PSK : WIFI_AUTH_OPEN;
    wifi_config.sta.sae_pwe_h2e = WPA3_SAE_PWE_BOTH;

    ESP_RETURN_ON_ERROR(esp_wifi_set_mode(WIFI_MODE_STA), TAG, "esp_wifi_set_mode failed");
    ESP_RETURN_ON_ERROR(esp_wifi_set_config(WIFI_IF_STA, &wifi_config), TAG, "esp_wifi_set_config failed");
    ESP_ERROR_CHECK_WITHOUT_ABORT(esp_wifi_set_ps(WIFI_PS_NONE));
    ESP_RETURN_ON_ERROR(esp_wifi_start(), TAG, "esp_wifi_start failed");

    ESP_LOGI(TAG, "Wi-Fi connecting to %s", CONFIG_APP_WIFI_SSID);
    return ESP_OK;
}

static esp_err_t post_state(const app_state_t *state, bool log_success)
{
    if (state == NULL || strlen(CONFIG_APP_MAIN_TERMINAL_URL) == 0) {
        return ESP_ERR_INVALID_STATE;
    }

    char payload[512];
    const char *state_text = state->fall_detected ? "fall" : "normal";
    float prob = state->fall_detected ? 1.0f : 0.0f;
    int len = snprintf(payload, sizeof(payload),
                       "{"
                       "\"sensor\":\"ld6002c_fall_radar\","
                       "\"node_id\":\"%s\","
                       "\"time_ms\":%" PRId64 ","
                       "\"alarm\":%s,"
                       "\"fall_detected\":%s,"
                       "\"state\":\"%s\","
                       "\"source\":\"%s\","
                       "\"fall_probability\":%.1f,"
                       "\"smooth_probability\":%.1f,"
                       "\"threshold\":0.5,"
                       "\"effective_threshold\":0.5,"
                       "\"motion_ok\":true,"
                       "\"samples\":%" PRIu32 ","
                       "\"frames\":%" PRIu32 ","
                       "\"falls\":%" PRIu32 ","
                       "\"header_errors\":%" PRIu32 ","
                       "\"data_errors\":%" PRIu32
                       "}",
                       CONFIG_APP_NODE_ID,
                       now_ms(),
                       state->fall_detected ? "true" : "false",
                       state->fall_detected ? "true" : "false",
                       state_text,
                       state->source[0] ? state->source : "-",
                       prob,
                       prob,
                       state->frame_count,
                       state->frame_count,
                       state->fall_count,
                       state->header_error_count,
                       state->data_error_count);

    if (len <= 0 || len >= (int)sizeof(payload)) {
        return ESP_ERR_INVALID_SIZE;
    }

    esp_http_client_config_t config = {
        .url = CONFIG_APP_MAIN_TERMINAL_URL,
        .timeout_ms = CONFIG_APP_HTTP_TIMEOUT_MS,
        .method = HTTP_METHOD_POST,
    };
    esp_http_client_handle_t client = esp_http_client_init(&config);
    if (client == NULL) {
        return ESP_ERR_NO_MEM;
    }

    esp_http_client_set_header(client, "Content-Type", "application/json");
    esp_http_client_set_post_field(client, payload, len);
    esp_err_t ret = esp_http_client_perform(client);
    int status = esp_http_client_get_status_code(client);
    esp_http_client_cleanup(client);

    if (ret == ESP_OK && status >= 200 && status < 300) {
        if (log_success) {
            ESP_LOGI(TAG, "POST ok fall=%d frames=%" PRIu32, state->fall_detected, state->frame_count);
        }
        return ESP_OK;
    }

    ESP_LOGW(TAG, "POST failed ret=%s status=%d url=%s",
             esp_err_to_name(ret), status, CONFIG_APP_MAIN_TERMINAL_URL);
    return ret == ESP_OK ? ESP_FAIL : ret;
}

static void report_task(void *arg)
{
    (void)arg;
    bool last_fall = false;
    bool last_valid = false;
    int64_t last_post_ms = 0;

    while (true) {
        vTaskDelay(pdMS_TO_TICKS(250));

        if (!s_wifi_ready) {
            continue;
        }

        app_state_t state = get_state_snapshot();
        if (!state.valid) {
            continue;
        }

        int64_t now = now_ms();
        bool changed = !last_valid || state.fall_detected != last_fall;
        bool interval_due = last_post_ms == 0 ||
                            now - last_post_ms >= CONFIG_APP_REPORT_INTERVAL_MS;
        if (!changed && !interval_due) {
            continue;
        }

        esp_err_t ret = post_state(&state, changed || state.fall_detected);
        if (ret == ESP_OK) {
            last_post_ms = now;
            last_fall = state.fall_detected;
            last_valid = true;
        }
    }
}

static void status_task(void *arg)
{
    (void)arg;
    while (true) {
        app_state_t state = get_state_snapshot();
        ESP_LOGI(TAG,
                 "STAT wifi=%d valid=%d fall=%d source=%s frames=%" PRIu32
                 " falls=%" PRIu32 " hdr_err=%" PRIu32 " data_err=%" PRIu32,
                 s_wifi_ready,
                 state.valid,
                 state.fall_detected,
                 state.source[0] ? state.source : "-",
                 state.frame_count,
                 state.fall_count,
                 state.header_error_count,
                 state.data_error_count);
        vTaskDelay(pdMS_TO_TICKS(5000));
    }
}

void app_main(void)
{
    ESP_LOGI(TAG, "LD6002C fall node starting");
    ESP_LOGI(TAG, "Target URL: %s", CONFIG_APP_MAIN_TERMINAL_URL);

    ESP_ERROR_CHECK(radar_start());
    ESP_ERROR_CHECK(wifi_start());

    xTaskCreate(radar_rx_task, "radar_rx", 4096, NULL, 8, NULL);
    xTaskCreate(tx2_poll_task, "tx2_poll", 2048, NULL, 5, NULL);
    xTaskCreate(report_task, "report", 6144, NULL, 5, NULL);
    xTaskCreate(status_task, "status", 3072, NULL, 3, NULL);

#if CONFIG_APP_LD6002C_QUERY_FIRMWARE_ON_BOOT
    vTaskDelay(pdMS_TO_TICKS(1500));
    esp_err_t ret = tf_send(LD6002C_TYPE_FIRMWARE, NULL, 0);
    if (ret != ESP_OK) {
        ESP_LOGW(TAG, "firmware query failed: %s", esp_err_to_name(ret));
    }
#endif
}

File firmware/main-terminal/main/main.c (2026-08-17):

#include <stdbool.h>
#include <stdint.h>
#include <stdio.h>
#include <string.h>
#include <time.h>

#include "bsp/esp32_p4_function_ev_board.h"
#include "esp_err.h"
#include "esp_heap_caps.h"
#include "esp_log.h"
#include "esp_system.h"
#include "esp_timer.h"
#include "freertos/FreeRTOS.h"
#include "freertos/idf_additions.h"
#include "freertos/task.h"
#include "lvgl.h"

#include "app_audio_input.h"
#include "app_cloud_asr.h"
#include "app_cloud_context.h"
#include "app_cloud_llm.h"
#include "app_cloud_tts.h"
#include "app_csi_receiver.h"
#include "app_k230_vision.h"
#include "app_network.h"
#include "app_radar.h"
#include "app_vitals_history.h"
#include "app_weather.h"
#include "app_voice_output.h"

static const char *TAG = "voice_agent_ui";

#ifndef CONFIG_APP_SIM800_ENABLE
#define CONFIG_APP_SIM800_ENABLE 0
#endif

#ifndef CONFIG_APP_SIM800_EMERGENCY_PHONE
#define CONFIG_APP_SIM800_EMERGENCY_PHONE ""
#endif

#ifndef CONFIG_APP_SIM800_AUTO_SMS_ENABLE
#define CONFIG_APP_SIM800_AUTO_SMS_ENABLE 0
#endif

#ifndef CONFIG_APP_SIM800_AUTO_CALL_ENABLE
#define CONFIG_APP_SIM800_AUTO_CALL_ENABLE 0
#endif

#define APP_EMERGENCY_BUTTONS_ENABLE CONFIG_APP_SIM800_ENABLE

#if CONFIG_APP_SIM800_ENABLE
#include "app_sim800.h"
#endif

#define C_BG       0xF7F9FC
#define C_SURFACE  0xFFFFFF
#define C_BORDER   0xE5EAF2
#define C_TEXT     0x172033
#define C_MUTED    0x667085
#define C_BLUE     0x2F6BFF
#define C_GREEN    0x0FA36B
#define C_AMBER    0xD08B00
#define C_RED      0xD92D20
#define C_HEART    0xE5486D
#define C_BREATH   0x1B8A7A

#define AI_ADVICE_TTS_MAX_BYTES 420
#define FALL_FUSION_ALERT_COOLDOWN_MS 15000
#define FALL_FUSION_PRIMARY_SCORE 45
#define FALL_FUSION_AUX_SCORE 20
#define FALL_FUSION_THRESHOLD 65
#define FALL_POPUP_AUTO_CLOSE_MS 4200
#define NODE_STATUS_STALE_MS 10000
#define FALL_ALERT_TONE_COUNT 10
#define FALL_ALERT_TONE_MS 260
#define FALL_ALERT_TONE_GAP_MS 140
#define FALL_ALERT_SOUND_WAIT_TIMEOUT_MS 5500
#define FALL_CELLULAR_SETTLE_MS 200

#define TXT_NET_CONNECTED "\xE7\xBD\x91\xE7\xBB\x9C\xE5\xB7\xB2\xE8\xBF\x9E\xE6\x8E\xA5  %s"
#define TXT_NET_MISSING    "\xE7\xBD\x91\xE7\xBB\x9C\xE6\x9C\xAA\xE9\x85\x8D\xE7\xBD\xAE"
#define TXT_NET_CONNECTING "\xE7\xBD\x91\xE7\xBB\x9C\xE8\xBF\x9E\xE6\x8E\xA5\xE4\xB8\xAD"
#define TXT_NET_RECONNECT  "\xE7\xBD\x91\xE7\xBB\x9C\xE9\x87\x8D\xE8\xBF\x9E\xE4\xB8\xAD"
#define TXT_NET_DISABLED   "\xE7\xBD\x91\xE7\xBB\x9C\xE5\xB7\xB2\xE5\x85\xB3\xE9\x97\xAD"
#define TXT_NET_WAITING    "\xE7\xBD\x91\xE7\xBB\x9C\xE7\xAD\x89\xE5\xBE\x85\xE4\xB8\xAD"
#define TXT_LISTENING      "\xE6\xAD\xA3\xE5\x9C\xA8\xE8\x81\x86\xE5\x90\xAC"
#define TXT_RELEASE_ASR    "\xE6\x9D\xBE\xE5\xBC\x80\xE8\xAF\x86\xE5\x88\xAB"
#define TXT_MIC_ERROR      "\xE9\xBA\xA6\xE5\x85\x8B\xE9\xA3\x8E\xE9\x94\x99\xE8\xAF\xAF"
#define TXT_HOLD_TALK      "\xE6\x8C\x89\xE4\xBD\x8F\xE8\xAF\xB4\xE8\xAF\x9D"
#define TXT_ASR            "\xE6\xAD\xA3\xE5\x9C\xA8\xE8\xAF\x86\xE5\x88\xAB"
#define TXT_WAIT           "\xE8\xAF\xB7\xE7\xA8\x8D\xE7\xAD\x89"
#define TXT_ASR_FALLBACK   "\xE5\xBD\x95\xE9\x9F\xB3\xE6\x97\xB6\xE9\x95\xBF %u \xE6\xAF\xAB\xE7\xA7\x92\xEF\xBC\x8C\xE4\xBD\x86\xE8\xAF\xAD\xE9\x9F\xB3\xE8\xAF\x86\xE5\x88\xAB\xE6\x9A\x82\xE6\x97\xB6\xE4\xB8\x8D\xE5\x8F\xAF\xE7\x94\xA8\xE3\x80\x82\xE8\xAF\xB7\xE7\x94\xA8\xE4\xB8\xAD\xE6\x96\x87\xE6\xB8\xA9\xE5\x92\x8C\xE5\x9C\xB0\xE8\xAF\xA2\xE9\x97\xAE\xE8\x80\x81\xE4\xBA\xBA\xE9\x9C\x80\xE8\xA6\x81\xE4\xBB\x80\xE4\xB9\x88\xE5\xB8\xAE\xE5\x8A\xA9\xE3\x80\x82"
#define TXT_NET_NOT_READY  "\xE7\xBD\x91\xE7\xBB\x9C\xE6\x9C\xAA\xE5\xB0\xB1\xE7\xBB\xAA"
#define TXT_THINKING       "\xE6\xAD\xA3\xE5\x9C\xA8\xE6\x80\x9D\xE8\x80\x83"
#define TXT_REPEAT         "\xE6\x88\x91\xE5\x9C\xA8\xE5\x91\xA2\xEF\xBC\x8C\xE8\xAF\xB7\xE5\x86\x8D\xE8\xAF\xB4\xE4\xB8\x80\xE9\x81\x8D\xE3\x80\x82"
#define TXT_SPEAKING       "\xE6\xAD\xA3\xE5\x9C\xA8\xE5\x9B\x9E\xE7\xAD\x94"
#define TXT_READY          "\xE5\x87\x86\xE5\xA4\x87\xE5\xB0\xB1\xE7\xBB\xAA"
#define TXT_PLAY_ERROR     "\xE6\x92\xAD\xE6\x94\xBE\xE9\x94\x99\xE8\xAF\xAF"
#define TXT_BUSY           "\xE6\xAD\xA3\xE5\x9C\xA8\xE5\xA4\x84\xE7\x90\x86"
#define TXT_TASK_ERROR     "\xE4\xBB\xBB\xE5\x8A\xA1\xE5\xA4\xB1\xE8\xB4\xA5"
#define TXT_PROCESSING     "\xE5\xA4\x84\xE7\x90\x86\xE4\xB8\xAD"
#define TXT_ANALYZING      "\xE6\xAD\xA3\xE5\x9C\xA8\xE5\x88\x86\xE6\x9E\x90"
#define TXT_AI_ADVICE      "AI\xE5\xBB\xBA\xE8\xAE\xAE"
#define TXT_ONE_TAP        "\xE4\xB8\x80\xE9\x94\xAE\xE6\x92\xAD\xE6\x8A\xA5"
#define TXT_PHONE_HELP     "\xE7\x94\xB5\xE8\xAF\x9D\xE6\xB1\x82\xE5\x8A\xA9"
#define TXT_SMS_HELP       "\xE7\x9F\xAD\xE4\xBF\xA1\xE6\xB1\x82\xE5\x8A\xA9"
#define TXT_ONE_TAP_CALL   "\xE4\xB8\x80\xE9\x94\xAE\xE6\x8B\xA8\xE6\x89\x93"
#define TXT_ONE_TAP_SEND   "\xE4\xB8\x80\xE9\x94\xAE\xE5\x8F\x91\xE9\x80\x81"
#define TXT_CALLING        "\xE6\x8B\xA8\xE5\x8F\xB7\xE4\xB8\xAD"
#define TXT_SENDING        "\xE5\x8F\x91\xE9\x80\x81\xE4\xB8\xAD"
#define TXT_CALLED         "\xE5\xB7\xB2\xE6\x8B\xA8\xE5\x8F\xB7"
#define TXT_SENT           "\xE5\xB7\xB2\xE5\x8F\x91\xE9\x80\x81"
#define TXT_HELP_FAILED    "\xE6\xB1\x82\xE5\x8A\xA9\xE5\xA4\xB1\xE8\xB4\xA5"
#define TXT_PHONE_EMPTY    "\xE5\x8F\xB7\xE7\xA0\x81\xE6\x9C\xAA\xE5\xA1\xAB"
#define TXT_SIM_WAIT       "\xE6\xA8\xA1\xE5\x9D\x97\xE7\xAD\x89\xE5\xBE\x85"
#define TXT_MANUAL_HELP    "\xE6\x89\x8B\xE5\x8A\xA8\xE6\xB1\x82\xE5\x8A\xA9"
#define TXT_AUTO_HELP      "\xE8\x87\xAA\xE5\x8A\xA8\xE6\x8A\xA5\xE8\xAD\xA6"
#define TXT_FALL_ALERT     "\xE6\xA3\x80\xE6\xB5\x8B\xE5\x88\xB0\xE8\xB7\x8C\xE5\x80\x92"
#define TXT_VITAL_ALERT    "\xE7\x94\x9F\xE5\x91\xBD\xE4\xBD\x93\xE5\xBE\x81\xE5\xBC\x82\xE5\xB8\xB8"
#define TXT_DATA_MISSING   "\xE6\x95\xB0\xE6\x8D\xAE\xE6\x9C\xAA\xE7\xA8\xB3"
#define TXT_ADVICE_FALLBACK "\xE6\x9A\x82\xE6\x97\xB6\xE6\x97\xA0\xE6\xB3\x95\xE8\xBF\x9E\xE6\x8E\xA5" "AI" "\xEF\xBC\x8C\xE8\xAF\xB7\xE4\xBF\x9D\xE6\x8C\x81\xE8\xA7\x84\xE5\xBE\x8B\xE4\xBD\x9C\xE6\x81\xAF\xE3\x80\x81\xE9\x80\x82\xE9\x87\x8F\xE9\xA5\xAE\xE6\xB0\xB4\xEF\xBC\x8C\xE5\xA4\x96\xE5\x87\xBA\xE5\x89\x8D\xE5\x85\xB3\xE6\xB3\xA8\xE5\xA4\xA9\xE6\xB0\x94\xEF\xBC\x9B\xE5\xA6\x82\xE6\x9C\x89\xE6\x98\x8E\xE6\x98\xBE\xE4\xB8\x8D\xE9\x80\x82\xEF\xBC\x8C\xE8\xAF\xB7\xE5\x8F\x8A\xE6\x97\xB6\xE8\x81\x94\xE7\xB3\xBB\xE5\xAE\xB6\xE4\xBA\xBA\xE6\x88\x96\xE5\x8C\xBB\xE7\x94\x9F\xE3\x80\x82"
#define TXT_HEART_TITLE    "\xE5\xBD\x93\xE5\x89\x8D\xE5\xBF\x83\xE7\x8E\x87"
#define TXT_BREATH_TITLE   "\xE5\x91\xBC\xE5\x90\xB8\xE7\x8E\x87"
#define TXT_UNIT_BPM       "\xE6\xAC\xA1/\xE5\x88\x86"
#define TXT_HISTORY_TITLE  "\xE8\xBF\x91\xE4\xBA\x94\xE5\xA4\xA9\xE5\xB9\xB3\xE5\x9D\x87"
#define TXT_HISTORY_FMT    "%s  \xE5\xBF\x83%s  \xE5\x91\xBC%s"
#define TXT_TIME_WAIT      "\xE6\x97\xB6\xE9\x97\xB4\xE5\x90\x8C\xE6\xAD\xA5\xE4\xB8\xAD"
#define TXT_WEATHER_WAIT   "\xE5\xA4\xA9\xE6\xB0\x94\xE8\x8E\xB7\xE5\x8F\x96\xE4\xB8\xAD"
#define TXT_HUMIDITY_FMT   "\xE6\xB9\xBF\xE5\xBA\xA6 %d%%"
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
